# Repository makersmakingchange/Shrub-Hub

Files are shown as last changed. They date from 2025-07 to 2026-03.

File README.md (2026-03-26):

<!--- Open Source Assistive Technology: GitHub Readme Template Version 1.2 (2024-May-27)  --->

<!--- TEMPLATE INTRODUCTION --->

<!--- INSTRUCTIONS --->
<!--- This is a markdown template for creating the README.md file in a GitHub repository. This file is rendered and displayed automatically when someone visits the repository.

This document includes helper text that will not be displayed when rendered. Any text between the less-than sign + exclamation mark + three hyphen-minus (<!---) and matching three hyphen-minus + greater-than sign will not be displayed. This helper text can be deleted once the corresponding section is completed.

This template has a number of fields that can be searched and replaced with other text:
 - <Repository_Link> Replace this with the web address for the repository. e.g., (e.g., https://github.com/makersmakingchange/Open-Wobble-Switch))
 - <MMCWebLink> This is the website address including an alphanumeric id for the Makers Making Change Website. e.g., 01tJR000000698oYAA. This will come from MMC staff. 
Any text that is currently holding a space / is an instruction for the person filling in the README is in all capitals, to make it easier to see them in a rendered version.

--->
 
<!--- TITLE --->
# Shrub Hub
<!--- Should match the name of the GitHub repository. Choose something descriptive rather than whimsical.  --->

## Overview
<!--- A brief summary of the project. What it does, who it is for, how much it costs. --->
The Shrub Hub is an digital switch interface that allows a user to connect up to three 3.5mm assistive switches to a digital device like a computer or mobile phone. It has five modes, and can send keystrokes, mouse clicks, and media control commands, with five outputs per mode. It is designed to provide digital access to users using assistive switches, and to be low cost and very easy to build.

It is designed for use by those who have difficulty using traditional input devices like a computer mouse and may be especially useful for those with limited finger or hand dexterity.

The device is comprised of off-the-shelf electronics and 3D printed parts. There is no soldering or complicated assembly involved in building the device.

The Shrub Hub is open assistive technology (OpenAT). Under the terms of the open source licenses, the device may be built, used, and improved upon by anyone.

The overall cost of materials is about $35 (plus $8 for component shipping).

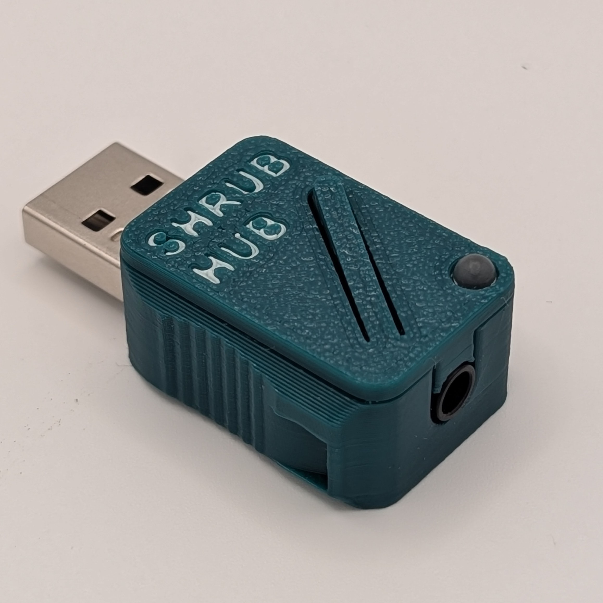
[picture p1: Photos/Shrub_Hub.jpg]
A Shrub Hub digital assistive switch interface consisting of a 3D printed enclosure with a USB-A connection on one end and a TRRS jack on the other.

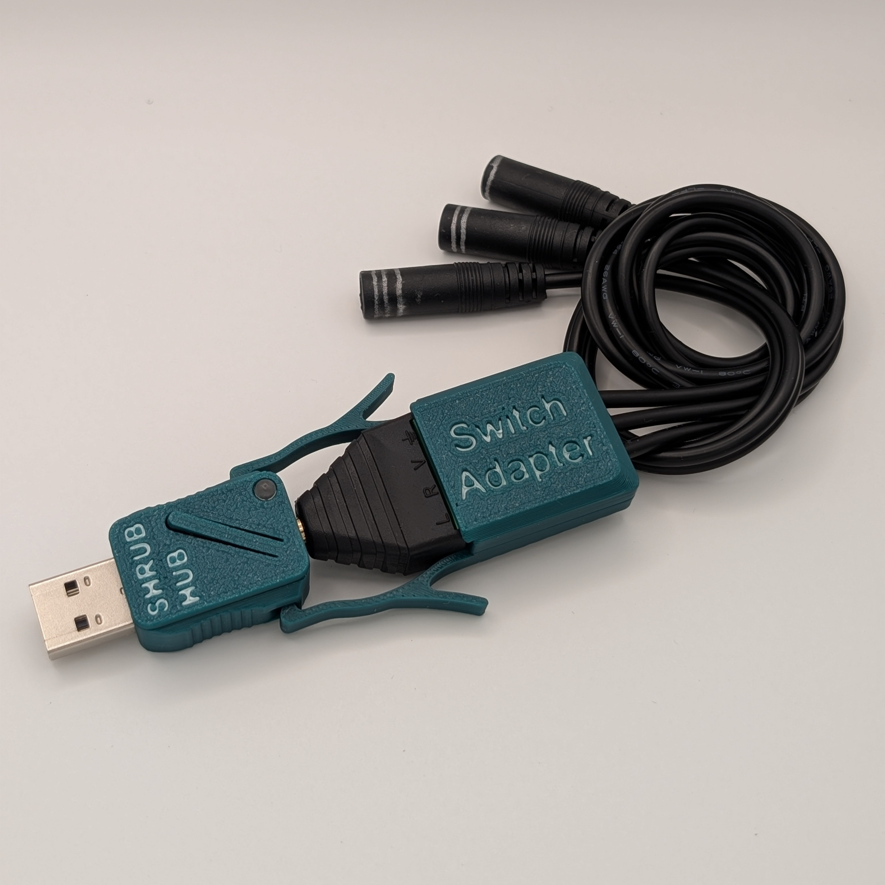
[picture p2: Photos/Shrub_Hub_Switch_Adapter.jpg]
A Shrub Hub with a 3-to-1 Switch Adapter attached to the TRRS connection on the Shrub Hub. The Switch Adapter has three cables attached, each with a 3.5 mm mono jack for connecting an assistive switch.

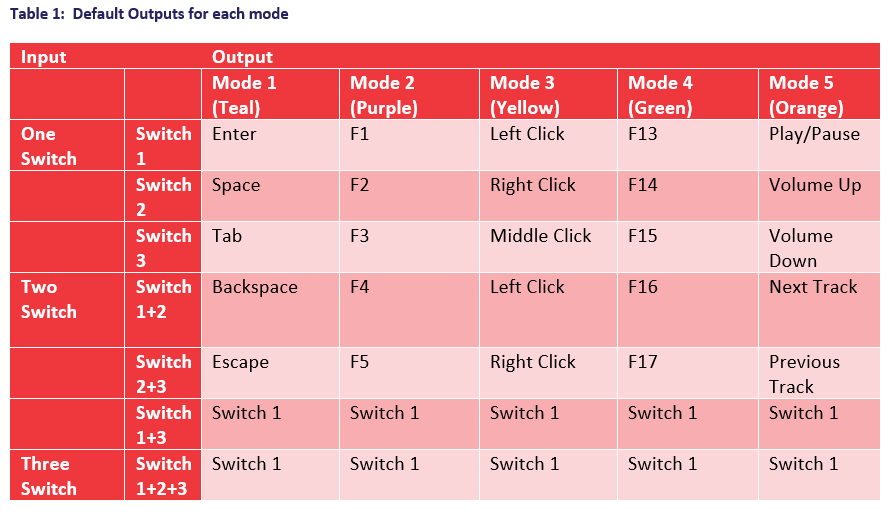
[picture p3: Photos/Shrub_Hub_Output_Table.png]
Table of Shrub Hub outputs.


## Makers Making Change Assistive Device Library
https://www.makersmakingchange.com/product/shrub-hub-digital-switch-interface/01tJR000009NpUT

## How to Obtain the Device
### 1. Do-it-Yourself (DIY) or Do-it-Together (DIT)

This is an open-source assistive technology, so anyone is free to build it. All of the files and instructions required to build the device are contained within this repository. Refer to the Maker Guide below.

### 2. Request a build of this device

You may also submit a build request through the [Makers Making Change Assistive Device Library Listing](<https://www.makersmakingchange.com/product/shrub-hub-digital-switch-interface/01tJR000009NpUT>) to have a volunteer maker build the device. As the requestor, you are responsible for reimbursing the maker for the cost of materials and any shipping.

### 3. Build this device for someone else

If you have the skills and equipment to build this device, and would like to donate your time to create the device for someone who needs it, visit the [MMC Maker Wanted](https://makersmakingchange.com/maker-wanted/) section.

## Build Instructions
<!--- Outline the major steps required to create a build --->

### 1. Read through the Maker Guide

The [Maker Guide](/Documentation/Shrub_Hub_Maker_Guide.pdf)  contains all the necessary information to build this device, including tool lists, assembly instructions, programming instructions and testing.

### 2. Order the Off-The-Shelf Components

The [Bill of Materials](/Documentation/Shrub_Hub_BOM.xlsx) lists all of the parts and components required to build the device.

### 3. Print the 3D Printable components

All of the files and individual print files can be found in the [/Build_Files/3D_Printing_Files](/Build_Files/3D_Printing_Files/) folder.

### 4. Assemble the Shrub Hub

Reference the Assembly Guide section of the [Maker Guide](/Documentation/Shrub_Hub_Maker_Guide.pdf) for the tools and steps required to build the device.

## How to improve this Device
As open source assistive technology, you are welcomed and encouraged to improve upon the design. 

## Files
### Documentation
<!--- Update the name, link, and version for documentation --->
| Document | Version | Link |
|---|---|---|
| Design Rationale | 1.0 | [Shrub_Hub_Design_Rationale](/Documentation/Shrub_Hub_Design_Rationale.pdf) |
| Maker Guide | 1.0 | [Shrub_Hub_Maker_Guide](/Documentation/Shrub_Hub_Maker_Guide.pdf) |
| Bill of Materials | 1.0 | [Shrub_Hub_Bill_of_Materials](/Documentation/Working_Documents/Shrub_Hub_BOM.xlsx) |
| User Guide | 1.0 | [Shrub_Hub_User_Guide](/Documentation/Shrub_Hub_User_Guide.pdf) |
| Quickstart Guide | 1.0 | [Shrub_Hub_Quickstart_Guide](/Documentation/Shrub_Hub_Quickstart_Guide.pdf) |
| Changing Outputs Guide| 1.0 | [Shrub_Hub_Changing_Outputs_Guide](/Documentation/Shrub_Hub_Changing_Outputs_Guide.pdf) |
| Changelog | 1.0 | [Changelog](CHANGES.txt) |

### Design Files
<!--- Include a copy of the original design files to facilitate easy editing and customization. Consider also including a generic format (e.g., STEP) --->
 - [CAD Files](/Design_Files/CAD_Design_Files)

### Build Files
<!--- Include a copy of the build files intended for manufacturing. This may include svg files for laser cutting, stl files for 3d printing, Gerber files for custom PCBs, and Arduino files for custom firmware. --->
 - [3D Printing Files](/Build_Files/3D_Printing_Files)
 - [Firmware Files](/Build/Firmware_Files)

## License
<!--- Add the year(s) for the copyright and the Designer Name. You may use the standard set of open licenses or choose your own for the hardware, software, and accompanying materials. --->
Copyright (c) 2026 Neil Squire Society.

This repository describes Open Hardware:
 - Everything needed or used to design, make, test, or prepare the Shrub Hub is licensed under the [CERN 2.0 Weakly Reciprocal license (CERN-OHL-W v2) or later](https://cern.ch/cern-ohl ) .
 - All software is under the [GNU General Public License v3.0 (GPL-3.0)](https://www.gnu.org/licenses/gpl.html).
 - Accompanying material such as instruction manuals, videos, and other copyrightable works that are useful but not necessary to design, make, test, or prepare the Shrub Hub are published under a [Creative Commons Attribution-ShareAlike 4.0 license (CC BY-SA 4.0)](https://creativecommons.org/licenses/by-sa/4.0/) .

You may redistribute and modify this documentation and make products using it under the terms of the [CERN-OHL-W v2](https://cern.ch/cern-ohl).
This documentation is distributed WITHOUT ANY EXPRESS OR IMPLIED WARRANTY, INCLUDING OF MERCHANTABILITY, SATISFACTORY QUALITY AND FITNESS FOR A PARTICULAR PURPOSE.
Please see the CERN-OHL-W v2 for applicable conditions.

Source Location: https://github.com/makersmakingchange/Shrub-Hub 

## Attribution
The Shrub Hub enclosure, software, and documentation was designed and created by the Neil Squire Society. 

The Shrub Hub incorporates the [Adafruit TRRS Trinkey - USB Key for Assistive Technology](https://www.adafruit.com/product/5954), a commercially available open source hardware device available for purchase through Adafruit and its distributors worldwide. The design of the TRRS Trinkey was a collaboration between [ATMakers.org](https://atmakers.org/) and [Adafruit](https://www.adafruit.com/). The hardware design files are released under the CC-BY-SA 3.0 license and are available at https://github.com/adafruit/Adafruit-TRRS-Trinkey-PCB. This device is also certified open hardware by the Open Source Hardware Association (OSHWA), certification [US002639](https://certification.oshwa.org/us002639.html).

The Shrub Hub is programmed in [CircuitPython](https://circuitpython.org/) using the [Mu Python Editor](https://codewith.mu/).

<!--- This is the attribution for the template. --->
The documentation template was created by Makers Making Change / Neil Squire Society. It is available at the following link: [https://github.com/makersmakingchange/OpenAT-Template](https://github.com/makersmakingchange/OpenAT-Template)

### Contributors
<!--- List the names of the people that contributed to the design. This could include the original source of the idea, designers, testers, documenters, etc. --->
 - Brad Wellington. Shrub Hub Enclosure, firmware, documentation. Neil Squire Society / Makers Making Change.
 - Bill Binko. TRRS Trinkey PCB design and Learning Guide. [ATMakers.org](https://atmakers.org/).
 - Chris Young. TRRS Trinkey PCB Design. [ATMakers.org](https://atmakers.org/).
 - Eric Chau. Testing. Neil Squire Society / Solutions.
 - Jake McIvor. Documentation, testing. Neil Squire Society / Makers Making Change.
 - Limor Fried. TRRS Trinkey PCB Design. [Adafruit](https://www.adafruit.com/).
 - Liz Clark. TRRS Trinkey Learning Guide. [Adafruit](https://www.adafruit.com/).
 - Jody Dickerson. Testing. Neil Squire Society / Solutions.
 - Josie Versloot. Testing. Neil Squire Society / Makers Making Change.
 - Stephan Dobri. Testing. Neil Squire Society / Makers Making Change.
 
## Open Source Hardware Certification

The Shrub Hub has been certified as open source hardware by the Open Source Hardware Association under the OSHWA UID [CA000073](https://certification.oshwa.org/ca000073.html).

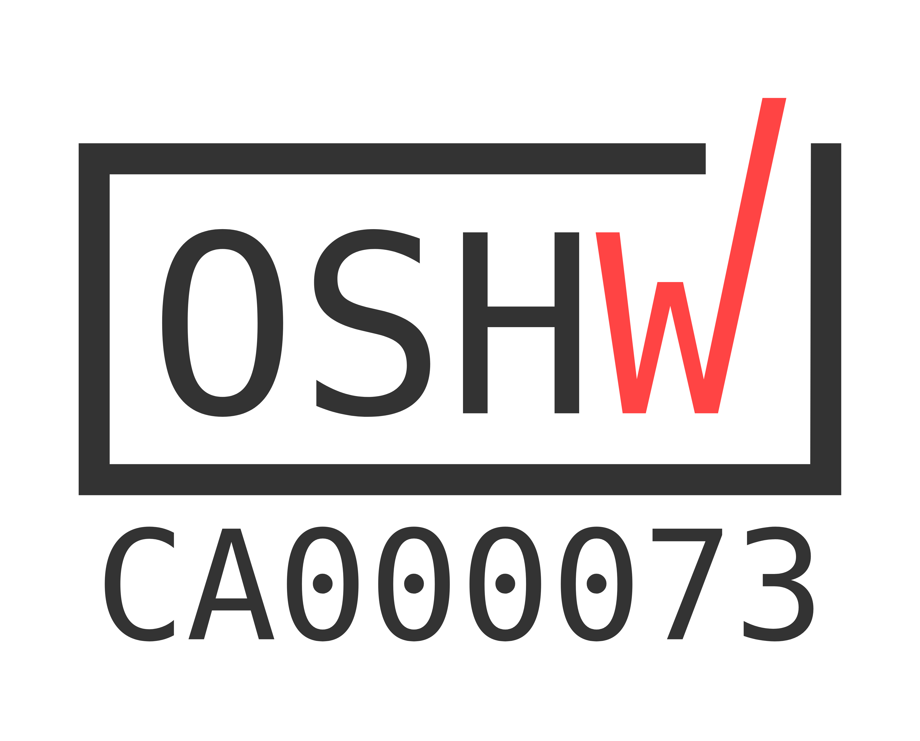
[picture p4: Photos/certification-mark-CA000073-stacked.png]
Open Source Hardware Certification Mark for Shrub Hub: CA000073
 

---

<!-- ABOUT MMC START -->
## About Makers Making Change
[Makers Making Change Logo](https://www.makersmakingchange.com/)

Makers Making Change is a program of [Neil Squire](https://www.neilsquire.ca/), a Canadian non-profit that uses technology, knowledge, and passion to empower people with disabilities.

Makers Making Change leverages the capacity of community based Makers, Disability Professionals and Volunteers to develop and deliver affordable Open Source Assistive Technologies.

 - Website: [www.MakersMakingChange.com](https://www.makersmakingchange.com/)
 - GitHub: [makersmakingchange](https://github.com/makersmakingchange)
 - Bluesky: [@makersmakingchange.bsky.social](https://bsky.app/profile/makersmakingchange.bsky.social)
 - Instagram: [@makersmakingchange](https://www.instagram.com/makersmakingchange)
 - Facebook: [makersmakechange](https://www.facebook.com/makersmakechange)
 - LinkedIn: [Neil Squire Society](https://www.linkedin.com/company/neil-squire-society/)
 - Thingiverse: [makersmakingchange](https://www.thingiverse.com/makersmakingchange/about)
 - Printables: [MakersMakingChange](https://www.printables.com/@MakersMakingChange)

### Contact Us
For technical questions, to get involved, or to share your experience we encourage you to [visit our website](https://www.makersmakingchange.com/) or [contact us](https://www.makersmakingchange.com/s/contact).
<!-- ABOUT MMC END -->

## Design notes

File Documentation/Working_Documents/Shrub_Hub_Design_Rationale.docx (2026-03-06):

# Overview

The Design Rationale is intended to provide designers and maker information about the design process and design decisions behind the development of the Shrub Hub, a cheap, easy to assemble switch access hub.

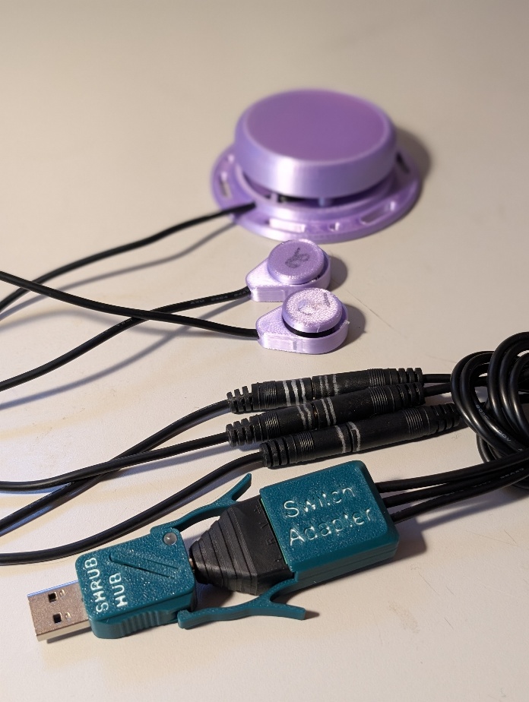
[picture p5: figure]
The Shrub Hub with the Switch Adapter connected to three assistive switches
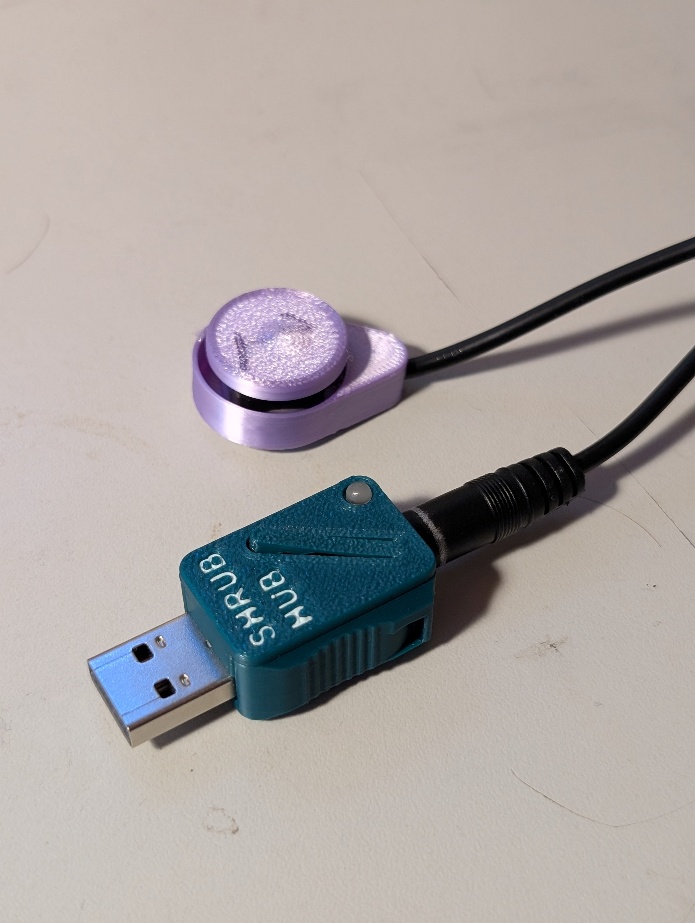
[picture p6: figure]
The Shrub Hub connected to a single assistive switch

# Introduction

Many people experience difficulty using standard input devices such as keyboards, mice, or touchscreens due to physical, cognitive, or sensory limitations. Assistive switches provide an alternative way to interact with technology by allowing users to control digital devices through simple, reliable actions such as pressing a button, activating a sensor, or triggering a switch with minimal movement.

To be useful, assistive switches must connect to computers, tablets, and other digital systems in a way that the device can recognize as input. While commercial switch interfaces exist to provide this digital access, they are often expensive, limited in customization, or difficult to obtain, creating a barrier for many users, families, schools, and support organizations.

This project presents a low-cost, easy-to-build digital switch interface designed to increase access to assistive switch technology. The device allows users to connect one or more assistive switches to common digital devices, enabling interaction with software, communication tools, and other technology. By focusing on affordability, simplicity, and accessibility, this design aims to reduce barriers to digital access and support a wider range of users in engaging with technology on their own terms.

The Shrub Hub is a USB Assistive Switch Interface based on the Adafruit TRRS Trinkey (https://www.adafruit.com/product/5954) hardware, a USB Key with a 3.5 mm jack and a microcontroller that was created based on a request from ATMakers (https://atmakers.org/), and the Adafruit Learning Guide (https://learn.adafruit.com/using-the-trrs-trinkey-as-an-assistive-technology-device/assembly) by Chris Young and Bill Binko.

# User and Interest-Holder Needs

ID | Need | Interest-Holder
UN01 | I need to be able to control my computer with minimal switches | Primary User
UN02 | A device that doesn’t require a soldering iron or PCB is easier to build | Maker
UN03 | I want a device that is easy to set up | Secondary User
UN04 | I want a device that I can customize to my needs | Primary User
UN05 | An inexpensive switch interface | Primary User, Secondary User

# Design Input

## Requirements

The goals and requirements outlined here can be used to assess if a device would meet the needs of a user and determine when a design is sufficient for release.

### Goals

G01 | Create a low-cost switch interface
G02 | Create an easy to build switch interface
G03 | Compatible with a computer without installing software
G04 | Create a portable switch interface

### Requirements

F01 | Device must accept at least two 3.5 mm switch inputs
F02 | Device must output HID keystrokes to the connected device

### Evaluation Criteria

1. Durability
2. Reliability
3. Minimize cost
4. Minimize print time
5. Minimize material usage
6. Minimize number of individual 3D printed parts

### Constraints

C01 | Device cannot use a custom PCB
C02 | Device cannot require soldering

## Research

Research was conducted as part of the update for the Switch Interface 101 resource.

### Commercially Available Options

Options that can be purchased but not made by a maker.

#### Swifty

Title / Name of device | Swifty
Link | https://www.orin.com/access/swifty/
Author | Origin Instruments
License | N/A
Cost | $99 USD

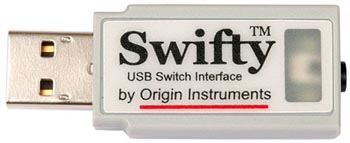
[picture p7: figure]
The Swifty Digital Switch interface on a white background

Figure 1: Swifty Switch Interface

The Swifty is a digital switch interface that can connect up to two 3.5 mm switches, or up to three wireless ‘Beam’ switches. It can be used to send keystrokes to a connected device for switch scanning or computer control.

Requirements Met | Requirements Unmet
F01, F02 | G01

##### Useful Design Features

Using three switches instead of two opens more options for computer control.

### DIY / Maker-Friendly Options

Options that can be made by a maker.

#### Rocket Switch

Title | Rocket Switch
Link | https://www.makersmakingchange.com/s/product/rocket-switch-interface/01tJR000000694SYAQ
Author | Neil Squire Society
License | Attribution-ShareAlike4.0 International
Cost | $50 CAD
Test Build (Y/N) | Y
Add to Library (Y/N) | Y

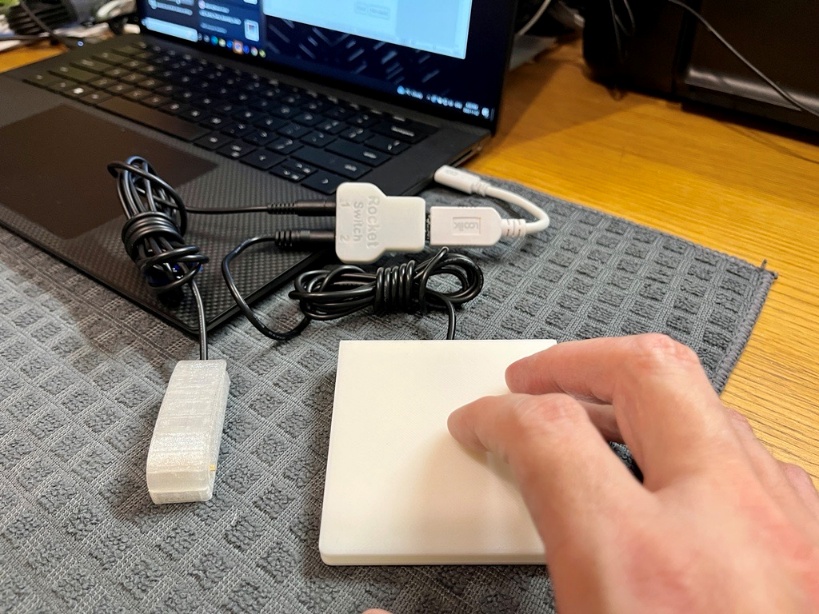
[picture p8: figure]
A hand pressing on a white assistive switch plugged into the Rocket Switch, which is plugged into a black laptop.

Figure 2: Rocket Switch Interface

The Rocket Switch is a USB switch interface that accepts up to two 3.5 mm switches to send keystrokes to the connected device.

Requirements Met | Requirements Unmet
G01, F01, F02 | C01, C02, G02

##### Useful Design Features

The modes feature of the Rocket Switch was taken and added to the Shrub Hub.

# Prototyping

## Initial Prototype

The initial version as published on the Adafruit site.

### Physical Component / Enclosure

The enclosure used on the device was provided by Adafruit. The version used was the FDM printed version, although they also provide an SLA compatible version.

The case can be found at the following link: The Case (https://learn.adafruit.com/adafruit-trrs-trinkey/downloads).

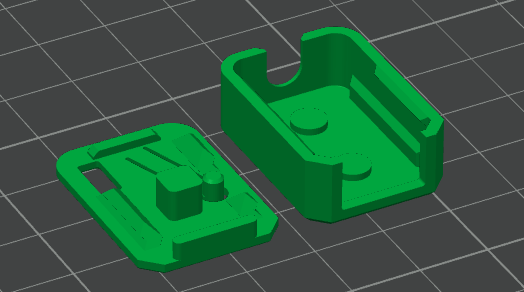
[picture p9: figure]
The TRRS Trinkey enclosure files open in a slicer program. The enclosure is in green, on a black grid background

Figure 3: Adafruit TRRS Trinkey Enclosure

### Electrical Components

Part | Image | Price | Link

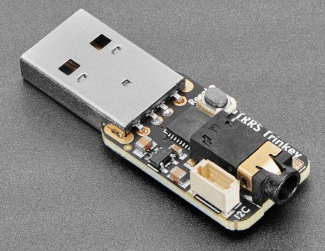
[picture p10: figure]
Angled Shot of the Adafruit TRRS Trinkey.

Adafruit TRRS Trinkey | | $9.95 USD | Link (https://www.adafruit.com/product/5954)

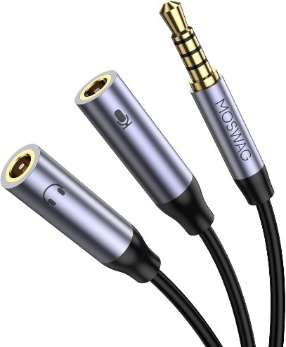
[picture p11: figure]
Close up of microphone splitter cable

Microphone Splitter Cable | | $10.99 CAD | Link

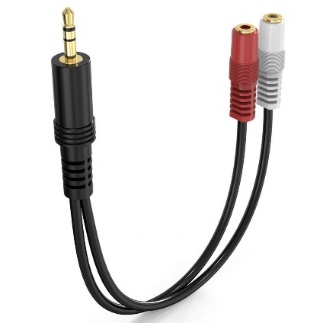
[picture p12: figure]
Close up of stereo to mono splitter cable

Stereo to Mono Splitter | | $9.99 CAD | Link

### Code Structure / Function

Code used for the initial version was the supplied code in the project repository called TRRS_Switch_Control (https://github.com/cyborg5/TRRS-Trinkey-Mouse-and-Keyboard-Emulator/tree/main/code) on GitHub.

The code scans the connected buttons and determines which output to send depending on the combination of switches pressed. The software recognizes the 3 individual switch presses and has an additional 2 outputs from chorded inputs, with another 2 chords recognized but not implemented.

## Prototype Decisions

Prototype | Decision (Abandon, Modify, Proceed) | Justification
Initial Prototype | Modify | Missing some functionality.

## Second Prototype

The second prototype was developed based on the feedback received from the user testing. It involves changes to both the enclosure and the firmware.

### Physical Components/Enclosure

An enclosure was developed to replace the one supplied by Adafruit for the TRRS Trinkey. This enclosure kept the same basic shape, with the snap-on lid with a flexible arm for the reset button, but several key changes were made.

The final enclosure has the lever arm, a light pipe for the NeoPixel LED, a USB-A connector, a TRRS plug, grippable spots on either side, and clip spots for attaching the TRRS breakout.

The TRRS breakout enclosure covers the TRRS terminal splitter and the cables. It prevents force on the cables from transferring to the screw terminals and makes a mechanical connection to the microcontroller that is sturdier than just the TRRS connection.

A new enclosure was developed that has the name of the device on it that includes a light pipe and covers the unused i2c port.

After user testing, a number of issues were raised about this enclosure. The testers found that:

- It could be difficult to unplug the device
- Light pipe was more ‘tactile’ than the reset button, leading to people pressing the light pipe
- Connection between Switch Adapter and the main device seemed weak
- Cable ties could be poorly trimmed by a maker and remain sharp

To resolve these issues, the enclosure was modified to raise the arm of the reset button beyond the plane of the lid so that it was more tactile, and a grip was added on either side of the enclosure to make it easier to remove. Two detents were also added to allow the Switch Adapter to attach better.

The Switch Adapter was redesigned to add two snap fit arms that attach to the enclosure, a set of internal deformable arms that secure the cables and replaced the cable tie with snap fit arms to hold the enclosure together.

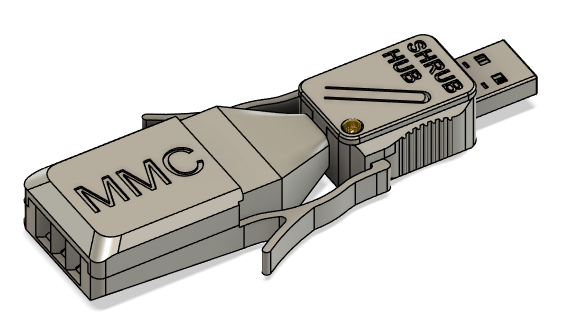
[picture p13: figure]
A CAD model of the Shrub Hub and Switch Adapter

Figure 4: Shrub Hub and Switch Adapter Enclosure

### Electrical Components

A piece of feedback received from the tester was that they would like to use the Shrub Hub with a single switch. The version that was given to the tester used the ring 2 as the common ground because that was the wiring used in the original Adafruit code, but plugging in a mono cable switch to this would short ring 1 and sleeve to ring 2, reading as switches 2 and 3 constantly being pressed down.

Version | L Terminal | R Terminal | V Terminal | Ground Terminal
Original | Switch 1 | Switch 2 | Ground | Switch 3
First Single Switch | Ground | Switch 1 | Switch 2 | Switch 3
Second Single Switch | Ground | Switch 2 | Switch 1 | Switch 3

To make this one switch version possible, the common ground was switched to the tip of the connector. This required the rewiring of the Switch Adapter to move the common ground, as well as some changes to the software. The ring 2 pin was changed to an input, while the tip was changed to an output. The switch detection function was modified to remove the tip, add ring 2, and change ring 1 to switch 1, ring 2 to switch 2, and sleeve to switch 3. Finally, since pressing a mono switch with this wiring would press all three switches, the chording needs to be added to handle this.

The original code recognized switch 6 (switch 1 + 3) and switch 7(all three switches) but since they were not included in the keystroke matrix, the code does not send switch 6 or switch 7 to the keystroke compiler. Since the mono cable switch detects as switch 7, an else statement was added to make both switch 6 and 7 use the switch 1 entry in the keystroke matrix. It is possible to also add entries for switch 6 and 7 to the keystroke matrix, but due to the memory issues that the microcontroller faces, it was decided to test the one switch version before dealing with the memory management.

Once these changes were made, the device was tested with the switch plugged directly into the microcontroller, and it behaved as expected. The device was tested again using the Switch Adapter to ensure that it still functioned as before, and no issues were detected.

The one thing that stood out was the different behaviour when using a switch with a TRS jack instead of a mono jack. When using the TRS jack, pressing the switch only connects the ring 2 and sleeve to ground instead of all three, which is read by the device as switch 5, which is already programmed into the device. This does not throw any errors, but a user who does not know the difference between a mono cable and TRS cable and is expecting switch 1 might be confused as to why they are getting switch 5, especially if switch 5 is a ‘non character’, like the escape key or function keys.

To resolve this issue, rings 1 and 2 were swapped, with ring 1 becoming switch 2 and ring 2 becoming switch 1. This causes a TRS switch to read as switch 6 when pressed, which behaves the same as switch 1, resolving the issue.

#### Alternate Parts Sourcing

When reviewing the parts in the Bill of Materials, we saw an opportunity to source the parts for the Switch Adapter through Digikey to simplify the ordering process and protect against the unreliability of Amazon sellers.

When looking for alternate parts on Digikey, we were unable to find exact replacements. Adafruit sold a TRRS terminal splitter, but it was significantly smaller than the one purchased from Amazon. There were also no direct equivalent to the mono cables, although there were similar 6ft long TRS cables that were ordered instead.

Once the parts arrived, a Switch Adapter was constructed and compared to the one made with Amazon parts. The first problem was the size of the TRRS splitter. The Adafruit on was significantly smaller, and requires a smaller screwdriver and the size of the openings on the terminal were much smaller. The Digikey cables were about a millimeter in diameter larger than the Amazon cables and had the ground wire as a wrapping of loose copper wires around the signal wires, wrapped in a metal foil.

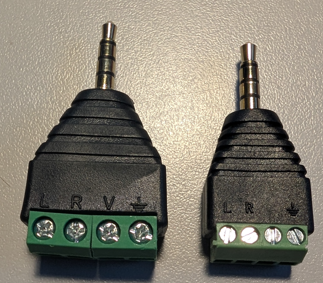
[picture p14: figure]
A side by side size comparison of the Amazon and Digikey TRRS terminals from the top
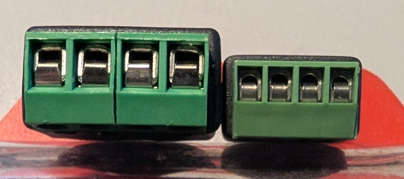
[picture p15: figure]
A side by side size comparison of the Amazon and Digikey TRRS terminals from the side

When attempting to build the Switch Adapter, there were several problems that appeared. The first problem was with the screw terminals, using a screwdriver that was slightly undersized for the terminal size strips the flathead connector on the terminal block, the screwdriver used needs to be the largest possible one that can fit in the hole for the screw. The terminals themselves are also undersized, unable to fit the twisted copper ground wire from one of the wires, let alone three. The cables were also worse than the Amazon equivalent, being six feet long and TRS, instead of two feet and mono. When cutting down the cables and trimming them, the ground connector was a collection of copper wires wrapped around the signal wires which were themselves wrapped in a metal foil. These took significantly more work to prepare than the precut and prestripped Amazon cables, and resulted in an extremely bulky and fraying ground cable that did not fit in the terminal.

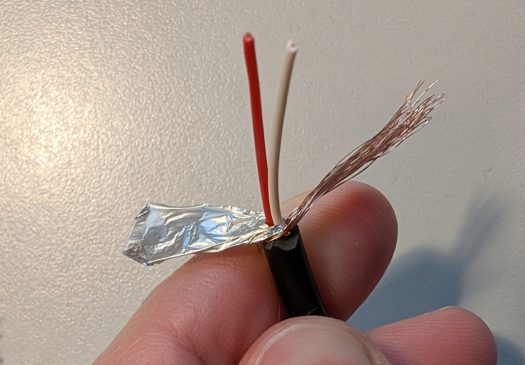
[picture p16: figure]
The digikey cable stripped
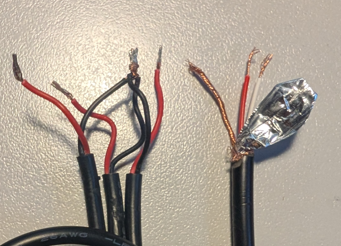
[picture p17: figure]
A side by side of the old cables vs the stripped amazon cable

After this, the decision was made to continue with the Amazon components for easier makeability.

#### Limitations of the TRRS Trinkey

While the TRRS Trinkey microcontroller is designed for use with Assistive technology, it does have its limitations.

The largest limitation that was encountered during development was the memory available on the board. The board has 32 KB of RAM, and this gets used quickly. When developing the code, this memory limit was frequently hit. This memory limit was reached when there was still between 1-2 KB of memory remaining on the board, due to memory fragmentation where there is memory still left on the board, but not a single continuous section of memory able to store whatever the user is currently trying to store. The CircuitPython program does not have any defragmentation tools, so this issue prevented the settings file from being on a separate user editable file, as there was not room on the board to add a function to read it into memory. There are garbage cleanup tools available however, which remove unused variables from memory to free up as much space as possible.

As a consequence of the limited memory, various libraries and sub library functions such as settings.toml, are not supported on the board.

Another limitation faced was the hardware on the board. The board has six pins tied to the TRRS jack, one for each ring, one to for the tip switch, and one for the ring 1 switch. There is also a reset button on the board, an i2c plug, and a NeoPixel. Beyond this, there is no way to connect to the microcontroller. When the idea was raised of a separate mode button on the device instead of holding a switch input, there was no way to easily do this. It would have required either adding a separate i2c button board, or holding the reset button while plugging in the board.

### Code Structure/Function

#### Time Monotonic Issue

A potential issue with the code is the use of time monotonic in the key press function. Time monotonic is used to track the duration of a keypress and determine when a key press reaches the mode change threshold. However, time monotonic is a 64-bit millisecond tick counter, and begins to lose precision after 2^22 milliseconds, (https://docs.circuitpython.org/en/latest/shared-bindings/time/) or about 1.165 hours. At 2^23 milliseconds, it will change every 2 milliseconds, and so on. More precise measurements of time, such as time.monotonic_ns() are not available on the Trinkey TRRS due to the lack of long integer support (https://learn.adafruit.com/adafruit-trrs-trinkey?view=all).

However, initial testing with leaving the device powered on for 16 hours it still took the same 4 seconds to change mode, which is roughly 2^25.8 millisecond, which should take 8 milliseconds per tick instead of 1, or 32 seconds to change the mode. More testing is needed to determine how the device will function after long periods of time powered on. A blink test was suggested, where the Neopixel turns off and on at regular intervals, and can be informally monitored over time to track the change in the timing.

#### Adding User Adjustable Settings

Figure 5: Supported CircuitPython Libraries for the Trinkey TRRS

One of the OFIs identifies was to add a settings file to allow the device to remember the mode after a reboot, and to make it easier for a clinician to change keystrokes or other settings without risking them breaking the code by changing the wrong section.

The requirements for a user adjustable setting file are:

- File must allow comments: Comments are needed to let the user know how to adjust the file, what they can and cannot change in the file
- File should be human readable: If the user is opening and changing the file, they should be able to read and understand the file
- File should be forgiving of simple formatting errors: Since the user will likely be editing the file in a text editor and not a proper IDE, an extra whitespace or newline shouldn’t break the file

In CircuitPython, the two main ways of doing this is with a settings.toml file, or with a text file that you parse.

In CircuitPython, a settings.toml file is used to separate settings from the main code.py file to allow the main code to be shared without also sharing personal information, such as passwords or network settings. It supports comments, and is essentially an extension of the main code file used to declare variables. Unfortunately, although it supports the OS library, the TRRS trinkey specifically does not support the use of settings.toml (https://docs.circuitpython.org/en/latest/shared-bindings/os/)

CircuitPython also allows for a txt file stored on the microcontroller to be read by the main program. While writing requires the board to be set to be read only to the computer, the text file can be read without changing settings on the board in a boot file.

If the data in the txt file is in JSON format, if can be easily read into the code using json.load. However, json does not support comments, is fairly rigid in its formatting, and is not very user parsable. JSON is also not available on the Trinkey TRRS (https://docs.circuitpython.org/en/latest/shared-bindings/support_matrix.html), a custom parser would need to be developed

YAML is a more user-friendly version of JSON that supports comments, but there is not a built in YAML parser the way that there is a JSON parser. A custom ‘YAML lite’ parser could be developed for the parts used in the keycode matrix.

Finally, a custom format can be developed for this specific use case, and a parser developed for it. This would take the most development time out of all the options, but provide the most flexibility and customizability. An initial test showed that integers read from a text file can be used to send keystrokes, but so far, keycode objects cannot be stored in the text file and used to send keystrokes. Having the keystrokes stored as integers instead of human readable words would run counter to the goal of having the keystrokes in a separate file to make it easier for a maker to modify the keystrokes.

Options | Pros | Cons
Settings.toml | - Supports comments - Written in Python, allows declaring the list exactly as it would be written in the main code - User can swap files to get a different set of keystrokes - User doesn’t have to open or make changes to the main file at all | - Not supported by the Trinkey TRRS
JSON | - Existing CircuitPython parser - User can swap files to get a different set of keystrokes - User doesn’t have to open or make changes to the main file at all | - Built in circuitpython JSON parser is not supported by Trinkey TRRS - Would need to develop a stripped back parser - Comments are not supported by the standard - Standard is not very human readable
YAML | - Standard supports comments - Standard is more human readable - User can swap files to get a different set of keystrokes - User doesn’t have to open or make changes to the main file at all | - Circuitpython does not have a built in YAML parser - Would need to develop a stripped back parser
Custom | - Would allow the creation of a standard that worked the best for the type of data we are storing - User can swap files to get a different set of keystrokes - User doesn’t have to open or make changes to the main file at all | - Would need to develop a custom parser - Can’t just read in keystrokes from file, need a way to convert them from strings
Leave keystroke matrix in | - Do not need to develop a custom parser - Do not need to develop a method to convert a string into a keycode object - Supports comments | - User will have to open and make changes to the main file

Recommendation

While breaking out the keycode and other user settings into a separate file is a good idea, the limitations of the TRRS Trinkey eliminate the best options. A settings.toml file would be the easiest, most user friendly method, but does not work with the Trinkey. The same issue is present with using a JSON file, as the Trinkey does not support the CircuitPython JSON parser.

This leaves us with developing a limited parser that can read the data in the text file. At this point, the format can either be JSON, YAML, or a custom data format. Using JSON or YAML, code can be reused from an existing parser, but stripped back to work with the limitations of the hardware.

Developing a custom parser would take significant development time, and require optimization to fit in the hardware limitations of the microcontroller. It would also need error handling and edge case detection.

The recommendation for the Shrub Hub is to leave the keystroke matrix in the code.py file. The fact that none of the standard plug and play options would work, requiring a custom developed parser vastly increases the amount of development time required, for a small improvement to the user experience.

Implementation

When trying to add a series of dictionaries to the main code to allow strings to be associated with the corresponding code object, the memory limit of the board was reached. After removing the dictionaries, the available memory left was revealed to be 2528 bytes. However, just the dictionaries measured in another file only took 1312 bytes.

Some research indicated that this may be due to fragmented memory, where there is not a large enough continuous location in memory for the dictionary, even though there is enough total room for them. (https://learn.adafruit.com/memory-saving-tips-for-circuitpython/reducing-memory-fragmentation)

Both declaring the dictionary at the beginning of the code, and frequent garbage collection were unable to make the dictionaries work. It also did not work when replacing the keycode.item calls with the integer values that they represent.

Another attempt was made to implement the settings closer to how they were handled in the Enabled Controller Mini CircuitPython version, with a section of the code dedicated to settings and separated from the rest of the code. In this section the individual button presses for each mode were broken out into their own variables, and all user modifiable settings were moved to this section. A declaration was added to then compile the keystroke matrix out of the component variables in the settings section. However, even this led to memory errors, as the addition of the extra variables for each keystroke entry caused memory issues.

Finally, an attempt was made to compile the code into a .mpy file, precompiling it to reduce the RAM usage and fragmentation using mpy-cross. The code was precompiled in powershell using “./mpy-cross code_name“ and loaded onto the Shrub Hub as a library. The main code file was then changed to be “import code_name” (this does not work if the .mpy file is named code.mpy). The code used for this was a version of the code that read the keystrokes from a text settings file. However, even after being precompiled, the code still did not have enough memory. Another attempt was made, removing the settings file and keeping the settings in the main file while everything else was kept in the library. This was also unsuccessful.

At this point it was decided that the original single file code should be used for the initial release.

#### Persistent Mode

To allow the mode to persist across reboots, a method was found to write to a non-volatile memory (nvm) byte array. While Adafruit says that it shouldn’t be possible to access non-volatile memory in circuitpython in non-express boards, the byte representing the mode was able to be stored to microcontroller.nvm[0].

# Testing

## Test Methods

### Test Switches

After connecting all switches to the commercial splitter cables, the device was plugged in and tested.

## Test Results

Initially, there was an issue where one key was consistently pressed down. This was determined to be caused by the mono TS cable used in the switches being consistently shorted by the microphone splitter cable. As a temporary workaround, the switch was replaced with another switch that used a TRS jack that would not be shorted.

Once the cables were working, it was found that the software worked as described, sending u/d/s/l/r when the correct switch/chord was pressed.

## User Testing

Two Shrub Hubs were sent to a pair of occupational therapists for testing. The initial pair sent were both programmed in Arduino but follow up instructions were sent to help with reprogramming the device in Circuit Python once that code had been developed. After the testers had the devices and used them with clients for about a month, a meeting was scheduled to get feedback on the devices

### Feedback Questions

General Questions

- Inputs
  - Is 3 inputs enough? Too few? Too many?
    - I think 3 is good, most people will remember 3 macros, ties into a next/back/select type system for a lot of different systems
  - Were there times that you needed additional inputs?
    - I have used more than 3 inputs for macros but have never yet needed it as buttons instead of a number pad or macro board
- Chording
  - Were you able to use the chording?
  - Were you able to test with a user? Were they able to use chording?
    - Not yet
  - Would it be beneficial to add 2 more chorded inputs (1+3, 1+2+3)
- Enclosure
  - Do you have any thoughts or issues with the enclosure of the TRRS Trinkey?
    - It’s good. I did try using it after putting lotion on my hands though and it was hard to remove, a few people might benefit from extra grip to pull it out, but mostly the user is not going to be the one connecting and disconnecting it.
    - A tactile label on the reset button would be helpful, visually it’s not that clear where to press
  - Do you have any thoughts or issues with the enclosure of the mono cable splitter?
    - I worry a little about the connection between the 2 getting bumped or pressed on and breaking the mono jack, it’s not very stable . This could also happen easily when thrown in a bag.
    - I worry a little that some creators won’t do a good job smoothing the ends of the cut zip ties, those can be really sharp if not cut carefully
    - It would be good to have the splitter mesh more with the trinkey, maybe with clips to prevent disconnection
  - Did you have any issues telling what mode the device was in/seeing the light pipe when the device was plugged in?
    - No, but younger user had trouble holding for 4 seconds (kept rushing it)
  - Was the size of the combined trinkey + splitter too big?
    - No. a right angle adapter could be used if needed?
- Getting the right input
  - Did you have any issues telling which switch input connected to which switch output?
    - No, your ring labels are clear and once the device is connected and programmed my memory moves to which switch color, not what number it is.
- Number of modes
  - Did you have any thoughts on the number of modes?
  - Did you find any of the modes unnecessary?
    - Never used 12345, too much chance for confusion
  - Were there any modes that you wanted but were not in the device?
    - mouseclicks
- Mouse clicks
  - Would mouse clicks be something you would want added?
    - Definitely, this is the most common use when pairing with something like a headmouse, and is effective to replace fine motor or finger control functions. Good for temporary disabilities
  - Would mouse movement be something you want added
    - Directional movement (pressing a button to move in the different directions)
      - I think that the other MMC joysticks already accomplish this
    - Morse mouse (Morse code to move the mouse around)
- Media control
  - Would media control (play/pause, skip, rewind, etc) be worth adding?
  - Would that be worth adding another mode for?
    - Yes, additional modes aren’t a burden for the user and most people wouldn’t reprogram them.
- Morse Code
  - Would morse code typing be worth adding?
    - I have only worked with one morse user and know of one more, both use a darcy/tandem master - I don’t think new users are adopting the technology very much.

Arduino Version

- Were there any issues changing the mode in Arduino mode?

Programming Circuit Python

- How would you describe the experience programming the hub with CircuitPython
  - Works well, it would be nice if there was a reminder of color within the matrix
- Were there any parts of programming the device that you found confusing or had questions about?
  - Double clicking button brings up a different boot menu
  - How to get out of boot menu/stop explorer opening folder

Circuit Python Version

- Were there any notable differences between this version and the Arduino version. If so, did they make the device better or worse
- Did you notice any issues with changing mode being slower after the device was plugged in for 2 hours? 4 hours?
  - Sorry, didn’t test it for that long yet ☹
- Were you able to change the keystrokes in the code?
  - Where you able to create a compound keystroke (like Win + H)

### Feedback Summary

- Three buttons is enough, a one button mode would be a nice addition
- Didn’t have an opportunity to test chording
- Trinkey was hard to remove from computer sometimes, enclosure is hard to grip
- Reset button should be more tactile/stand out more. Sometimes try to press the light pipe accidently since it sticks out more.
- Connection between splitter and hub is delicate, and worry about breaking it when throwing it into a bag
  - Maybe add some clips to make the splitter attach better
- Cable ties on splitter could be sharp if a maker doesn’t carefully trim them down
- Some younger users had difficulty holding it for 4 seconds and kept releasing too soon. Adding a blinking light when 4 seconds is up would help
- Right angle adapter might be useful but not necessary
- Ring labels on splitter are clear
- Didn’t use the 12345 mode, too much chance for confusion
- Really want the addition of mouse clicks
- Would want the addition of media control
- Don’t think that there’s much demand for morse typing
- When in circuitpython mode, device was easy to reprogram
- Would be nice to have a comment/reminder of the mode colour in each row of the keystroke matrix
- Accidently broke the code when trying to make changes, need to add a more in depth troubleshooting to the user guide about recognizing when the code is broken, since it is interpreted instead of compiled

OFIs

- Add gripable spots to the side of the enclosure
- Design a better enclosure for the splitter that does not rely on zip ties
- Create a stronger connection between the splitter and the hub
- Add mouse click mode
- Add media player mode
- Remove 12345 mode
- Improve troubleshooting section of user guide
- Better comments in the code
- Make it so the light flashes once 4 seconds holding the button is reached
- Make the reset button more tactile
- Save mode between reboots

# Design Output

## Naming

When choosing a name for the device, an effort was made to stay within the existing forest/tree theme for MMC joysticks and digital interfaces. A variety of names were brainstormed, such as Glade, Grove, Weald, and more names were suggested by the tester, such as Shrub, Arbor, Orchard, Leaf, and Twig.

Weald was eliminated first, as it was an obscure word that nobody knew. Grove was eliminated due to being the name of a connector by Seeed Studio, while Glade was eliminated to avoid overlap with the air freshener brand. From the remaining list of names, the name Shrub was chosen due to the connotations of being a small tree/plant.

The name of the add-on device that splits the TRRS jack into three mono cables was also something that needed to be determined. It was initially named the Switch Splitter, but the issue was raised that is sounded like a device that could be used to split one switch to instead control several devices. The following list of replacement names were brainstormed:

- Switch Adapter
- Splitzio
- Switch Breakout
- TripSplitz
- Switch Merger
- 3-in-1 Switcher
- 3-to-1 Switch
- 3-2-1 Switch
- 3-2-1/3-to-1 Merger

The decision was made to go with 3-to-1 Switch Adapter for this device.

## Detailed Design

### Overview

The device is comprised of two main parts, a TRRS Trinkey microcontroller in an enclosure, and a TRRS breakout connector that allows three assistive switches to be connected to the device. When connected to the computer, the device will send keystrokes when the connected buttons are pressed. It has five different modes with different sets of keystrokes, and the user can change between them by holding down a connected switch for four or more seconds. The different modes allow users to send screen navigation keystrokes such as space, tab, and enter, send the first five functions keys(F1-F5), perform mouse clicks, send the first five unused function keys(F13-F17) for custom hotkeys, and perform media control such as play/pause, volume up/down, and skip.

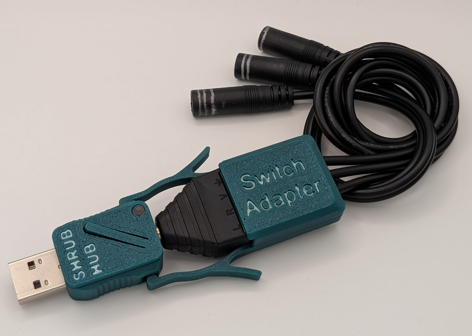
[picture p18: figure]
Final version of the Shrub Hub and Switch Adapter.

Figure 6: Finished Shrub Hub and Switch Adapter

#### Enclosure

Objectives:

1. Protects the internal board
2. Provides grip to more easily insert/remove the device.
3. Improves the aesthetics of the device
4. Provides a connection point for the Switch Adapter
5. Provides a place for labelling and branding

Requirements:

1. Hold the PCB securely
2. Show the mode LED
3. Provide access to the reset button

Criteria

1. As narrow as possible.
2. Minimal print time.
3. No or minimal tools required for assembly.
4. Aesthetic

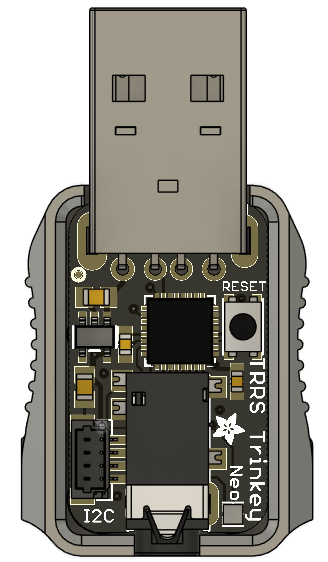
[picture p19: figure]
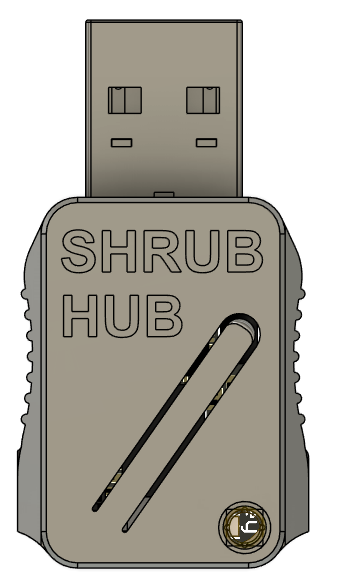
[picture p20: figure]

Figure 7: Shrub Hub with and without top of enclosure

The enclosure for the microcontroller is a two-part enclosure that uses a snap fit to connect the lid to the base. The microcontroller is held in place vertically by the fit of the two halves around the USB and TRRS connectors, and four pillars on the bottom that space the microcontroller from the bottom, and horizontally by the general shape of the base of the enclosure. There is ~0.23 mm of clearance between the walls of the enclosure and the sides of the PCB.

The enclosure keeps the flexible arm to activate the reset button from the original Adafruit enclosure, but the pillar that presses the reset button has deliberately been made too tall so the arm flexes out beyond the plane of the lid of the enclosure to provide a tactile locating feature to make it easier to press the reset button when the enclosure is not visible, such as when the device is plugged into the back of a computer.

A light pipe has been added to the lid of the enclosure, located over the microcontroller’s NeoPixel to allow the user to view the visual feedback from the light. The light pipe is held in place using a press fit.

Finally, the exterior of the enclosure has two concave detents with vertical ribs to make it easier to grip the enclosure while removing it from the computer, and two integrated snap fit pockets to connect to the Switch Adapter.

#### Switch Adapter

The TRRS Trinkey has a TRRS input. To use standard assistive switches with mono plugs, an adapter is required. There is a combination of commercially available adapters that can work, but they are expensive, only specific varieties will have the correct wiring, and the overall connection is not compatible with all assistive switches.

Using a custom adapter ensures that the device is compatible with all assistive switches. The adapter consists of an off-the-shelf TRRS terminal block, three mono cables with female jacks, and a 3D printed enclosure.

Objective

1. Provides an easy way to connect multiple mono switch connections to the TRRS input on the Shrub Hub

Requirements

1. Must be able to connect three 3.5 mm mono plugs in the correct wiring scheme to a 3.5 mm male TRRS plug.
2. Must be able to be assembled without soldering.
3. Mono switch connections must be labelled.

Criteria

1. Durable, reliable connection to Shrub Hub
2. Minimal size
3. Durability
4. Reliability

The Switch Adapter consists of a 3D printed enclosure, a screw terminal TRRS jack, and three female mono cables

The mono cables are attached to the screw terminals of the TRRS jack and allow the TRRS connection to be split out to the three mono cables with a common ground. The enclosure protects these connections and allows for the Switch Adapter to be more securely connected to the microcontroller enclosure.

The enclosure consists of two parts: a base that connects to the microcontroller enclosure and grips the mono cables; and a lid that attaches the enclosure to the TRRS jack. The two halves of the enclosure connect with a snap fit.

The base of the Switch Adapter has three primary features. The first feature is the two long arms that extend from the body of the splitter. When the TRRS jack is connected to the microcontroller, these arms clip into the detents in the body of the microcontroller enclosure and help to prevent the TRRS jack from being unplugged or coming loose. These attachment arms also feature two side arms that can be gripped to flex the enclosure arms to the side to detach them from the microcontroller enclosure. The second main feature of the base are the flexible arms that grip the three mono cables. Designed for use with 3mm mono cables, these arms flex out of the way, with the vertical ridges gripping the cable, preventing it from moving forwards or backwards. Finally, the base contains slots for the snap fit of the lid to attach.

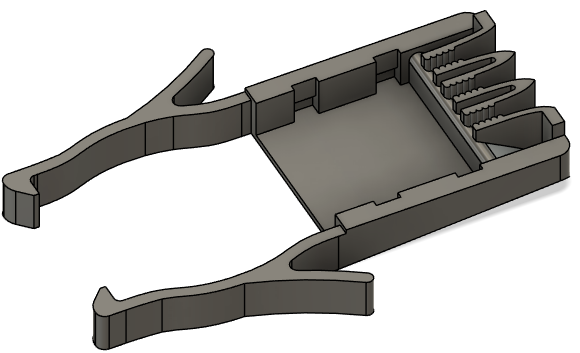
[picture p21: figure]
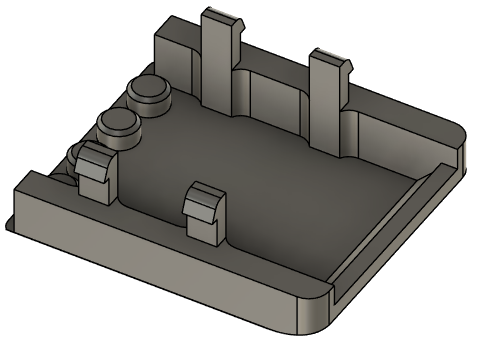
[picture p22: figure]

Figure 8: Top and Bottom of Switch Adapter Enclosure

The lid of the enclosure contains two main features, the snap fit arms that attach it to the base, and the four posts that help retain the enclosure on the splitter. The enclosure is assembled around the TRRS splitter, and the four posts are inserted into the holes of the screw terminal, preventing the enclosure from moving forwards or backwards relative to the TRRS jack. The enclosure is prevented from moving side to side by a combination of the posts and the fit of the enclosure around the jack and prevented from moving up and down by the fit of the enclosure around the jack.

### Electrical Components

After the issue with the mono cable switches shorting on the microphone splitter, an alternate splitter cable was created using a TRRS terminal jack and three pre stripped female mono cables. This option requires slightly more assembly but still does not require soldering. It is cheaper to build than the commercial splitter version and gets even cheaper when built in bulk.

Part | Image | Price | Link

Single Build

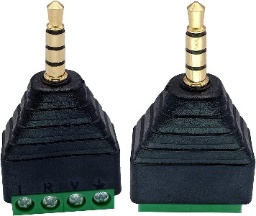
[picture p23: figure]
Two TRRS Terminal Jacks

TRRS Terminal | | $6.58/2 pack $3.28 Each | Link

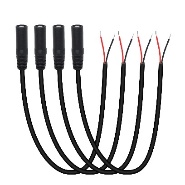
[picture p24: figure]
Four stripped mono cable jacks on a white background

Female Mono Cable | | $10.99/4 pack $2.75 Each | Link (http://www.amazon.ca/dp/B0BZWK7PLP)

Bulk Build

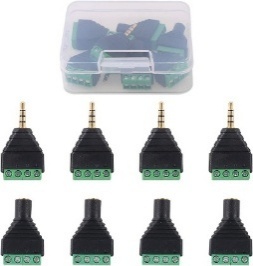
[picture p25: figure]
A plastic box full of TRRS Terminal jacks, with 8 more jacks laid out beneath it

TRRS Terminal | | $14.93/8 pack $1.86 Each | Link (https://www.amazon.ca/dp/B07KF8SRC3/)

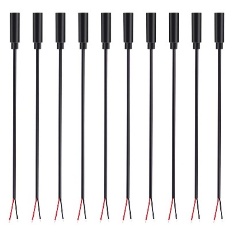
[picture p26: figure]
10 pre stripped mono cable jacks laid side by side.

Female Mono Cable | | $20.22/10 pack $2.02 Each | Link (https://www.amazon.ca/dp/B082VW97TT)

The final wiring of the TRRS adaptor is as follows, where the bolded section is the terminal on the TRRS plug, and the rest is the wire that is connected to it:

- L: Common ground for all three switches
- R: The signal cable for switch 2
- V: The signal cable for switch 1
- GND: The signal cable for switch 3

This configuration allows for a single switch to be plugged in to the Shrub Hub instead of the adapter and function as either Switch 6 or 7, depending on the cable type used on the single switch.

### Code Structure / Function

#### Overview

The code for the Shrub Hub is written in CircuitPython and can be easily loaded onto the device with minimal instructions, and settings easily changed. The code detects which combination of the three switches have been pressed and determines which keystrokes should be sent based on the combination of switches pressed.

#### Platform

The Shrub Hub was programmed using CircuitPython on the Mu IDE, as opposed to most MMC devices, which use ArduinoC. The decision was made to program the device in CircuitPython for several reasons. One of the largest reasons was to allow for the user to be able to change settings in the firmware easier, as the code is stored on the device and can be easily modified without needing to install anything. Programming in CircuitPython also allows the MMC team to build institutional knowledge on using CircuitPython and its limitations.

#### Operating Modes

The device currently has five different operating modes, based off the original operating modes of the Adafruit version, and feedback from the testers. The mode can be changed by holding down any connected switch for more than the mode change time, which by default is four seconds. Each mode by default has five different keystrokes, three of which are activated when pressing an individual switch, and two that are activated by pressing two switches at the same time. The default modes that the device is programed with are as follows:

- Mode 1: Enter/Space/Tab/Backspace/Escape
- Mode 2: F1/F2/F3/F4/F5
- Mode 3: Left Click/Right Click/Middle Click/Left Click/Right Click
- Mode 4: F13/F14/F15/F16/F17
- Mode 5: Play/Volume Up/Volume Down/Next Track/Previous Track

The keystrokes of mode one were chosen based on the research done on existing commercial hubs, as they were commonly found on most commercial hubs and can be used for basic computer navigation without needing any settings changed on the host device. Mode 2 keystrokes were taken from the MMC Enabled Controller. Mode 3 and 5 were added after feedback from testers, and mode 4 was added on the request of a tester who wanted unused keys that could be used with the AutoHotkey program to trigger different actions and programs.

After full release of the device one of the goals is to get feedback from users and clinicians about the range of keystrokes on the Shrub Hub and ensure that they meet the needs of the users.

#### Input Handling

When a switch is pressed, the NeoPixel is turned off, and the device waits until the switch is released. Once the switch has been released, if it was held for less than four seconds the device turns the NeoPixel back on and sends the appropriate output to the connected computer. If the switch was held for over four seconds, the mode changes, the colour of the NeoPixel changes, and no output is sent to the connected computer. It is important to note that the output is sent to the connected device when the switch is released, not when it is pressed.

The device checks for switch presses at 100Hz, or 100 times a second.

#### Operation

Once plugged in, the Shrub Hub reads the last stored mode from non-volatile memory, then enters the main loop. The main loop of the Shrub Hub firmware constantly checks to see if a button has been pressed. If it has, the program turns off the LED and checks to see which buttons have been held down and checks to see when they are released. Once the buttons have been held for longer than the mode change time, the LED comes back on. Once the buttons are released, if they were held for longer than the mode change time, the mode will change, the LED colour will update, the new mode will be logged to the non-volatile memory, and no keystroke will be sent. If the buttons were held for less than the mode change time, the buttons pressed will be sent to the keystroke compiler.

The keystroke compiler takes the buttons pressed and the mode and looks up the corresponding entry in the keycode matrix. The entry contains a number corresponding to the type of keystroke (keystroke, mouse click, or media control), as well as a series of keystrokes. From here, it will use the identifier number to determine which library to use and sequentially press and hold all the keys listed in the matrix entry. This is largely irrelevant for mouse and media control, which only use one key at a time, but allows combination keystrokes such as CTRL+C or CTRL+SHIFT+T. After all keys are pressed, the keystroke is sent, all keys are released, and the program returns to the main loop.

Currently, switches 1, 2, and 3 all have their own corresponding outputs, while the combination Switch 1+2 and switch 2+3 also have their own distinct outputs. Switches 1+3 and 1+2+3 send the same output as switch 1, as it allows for a single switch to be plugged directly into the TRRS jack on the Shrub Hub without the use of the Switch Adaptor and still function.

# Validation and Verification Plan

To verify and validate the Shrub Hub, we review the goals, requirements and constraints that were established at the beginning of the project and compare them with the finished device. At the beginning of the project, we established the following:

Goals

G01 | Create a low-cost switch interface
G02 | Create an easy to build switch interface

Functional Requirements

F01 | Device must accept up to two 3.5 mm switch inputs
F02 | Device must output HID keystrokes to the connected device

Constraints

C01 | Device cannot use a custom PCB
C02 | Device cannot require soldering

Now that the device is further along in development, we can compare it with the goals, requirements and constraints.

Goals

- G01: The Shrub Hub has a unit cost of $27.19 CAD and a total cost of $33.01 CAD, compared to the Rocket Switch, which has a unit cost of $21 and a total cost of $45. This makes the Shrub Hub cheaper for a single unit build, and similar for a bulk build to the Rocket Switch, which is the MMC budget switch interface. This is a pass.
- G02: The Shrub Hub can be assembled with no soldering and only requires a screwdriver to assemble the Switch Adapter. This is a pass.

Functional Requirements

- F01: The Shrub Hub can connect to three 3.5 mm switch inputs. This is a pass
- F02: The Shrub Hub sends three sets of five HID keystrokes, as well as a set of five mouse clicks and five media control commands. This is a pass

Constraints

- C01: The device does not require a custom PCB. This is a pass
- C02: The device does not require soldering to assemble. This is a pass.

After reviewing the goals, requirements, and constraints set out in the beginning of the project, the Shrub Hub meets all of them

This section defines the verification and validation (V&V) activities required to confirm that the device meets its design requirements, user and stakeholder needs, and applicable safety and performance expectations.

- Verification ensures the design was built correctly according to specifications.
- Validation ensures the right design was built, meeting user needs in real-world use.

## Verification

### Verification Objective

Confirm that all design requirements have been met through objective evidence such as inspection, analysis, or testing.

### Verification Methods

Common verification methods include:

- Inspection: Visual or measurement confirmation (e.g., enclosure dimensions, solder joints).
- Analysis: Analytical confirmation (e.g., thermal calculations, firmware memory usage).
- Test: Functional testing under controlled conditions (e.g., switch response time).
- Demonstration: Simple operational proof (e.g., assembly demonstration).

### Verification Matrix

Requirement ID | Requirement | Verification ID | Verification Method | Acceptance Criteria | Result / Status (Pass/fail, comment?) | Evidence Reference (linking to results/data that showed we passed the requirement)
N/A | Shrub Hub enclosure must be printable on a high-end printer (Bambu P1S, Prusa Mk4) | V01a | Demonstration | The enclosure can be printed on a high end printer with text visible and all features functional | Pass
N/A | Shrub Hub enclosure must be printable on an older printer (Ender 3) | V01b | Demonstration | The enclosure can be printed on an older printer with text visible and all features functional | Pass
N/A | Switch Adapter enclosure must be printable on a high end printer (Bambu P1S, Prusa Mk4) | V02a | Demonstration | The enclosure can be printed on a high end printer with text visible and all features functional | Pass
N/A | Switch Adapter enclosure must be printable on an older printer (Ender 3) | V02b | Demonstration | The enclosure can be printed on an older printer with text visible and all features functional | Pass
N/A | Reset button must not get stuck in use when printed on a high end printer (Bambu P1S, Prusa Mk4) | V03a | Demonstration | When pressing the reset button on the assembled device, the lever arm should spring back and not remain pressed | Pass
N/A | Reset button must not get stuck when printed on an older printer (Ender 3) | V03b | Demonstration | When pressing the reset button on the assembled device, the lever arm should spring back and not remain pressed | Pass
N/A | The reset button must last 1000 presses | V04 | Test | The reset button should be able to be pressed a thousand times and still work without getting stuck. | Pass
N/A | The reset button arm should still work after 1 month | V05 | Demonstration | The reset arm should not creep enough to stop working after a month | Pass
N/A | The device must be able to be cleaned with a damp cloth. | V06 | Demonstration | The Shrub Hub can be cleaned with a damp cloth. | Pass
N/A | The light pipe should be installable with less than TBR and more than TBR grams of force | V07 | Test | The user should be able to install the light pipe with less than TBR and more than TBR grams of force
N/A | The Shrub Hub enclosure must last 25 snap fit cycles | V08 | Test | The enclosure should be able to be installed and removed 25 times without breaking | Pass
N/A | The Switch Adapter enclosure must last 50 snap fit cycles | V09 | Test | The enclosure should be able to be installed and removed 50 times without breaking | Pass
N/A | The Shrub Hub must withstand a 100 cm drop onto concrete | V10 | Test | The Shrub Hub should be dropped from 100 cm onto concrete and inspected for damage | Pass
N/A | The Shrub Hub with Switch Adapter must withstand a 100 cm drop onto concrete | V11 | Test | The Shrub Hub with Switch Adapter should be dropped from 100 cm onto concrete and inspected for damage | Pass
| With a single mono switch connected, the Shrub Hub should send the first input of the active mode | V12a | Demonstration | Connect a mono switch to the Shrub Hub, press it and monitor the output. | Pass
| With a single TRS switch connected, the Shrub Hub should send the first input of the active mode | V12b | Demonstration | Connect a TRS switch to the Shrub Hub, press it and monitor the output. | Pass
| Holding any switch for more than the mode change time should change the mode | V13 | Demonstration | Connect a switch to the Shrub Hub, press it for more than the mode change time and verify that no output is sent and the mode changes. | Pass
| A switch connected to the switch 1 port of the Switch adapter should send the first input of the active mode | V14a | Demonstration | Connect a switch to the Switch Adapter port 1, press it and monitor the output. | Pass
| A switch connected to the switch 2 port of the Switch adapter should send the second input of the active mode | V14b | Demonstration | Connect a switch to the Switch Adapter port 2, press it and monitor the output. | Pass
| A switch connected to the switch 3 port of the Switch adapter should send the third input of the active mode | V14c | Demonstration | Connect a switch to the Switch Adapter port 3, press it and monitor the output. | Pass
| A switch connected to the switch 1 port of the Switch adapter pressed at the same time as a switch connected to the switch 2 port should send the fourth input of the active mode | V14d | Demonstration | Connect a switch to the Switch Adapter port 1 and one to port 2, press them and monitor the output. | Pass
| A switch connected to the switch 3 port of the Switch adapter pressed at the same time as a switch connected to the switch 2 port should send the fifth input of the active mode | V14e | Demonstration | Connect a switch to the Switch Adapter port 3 and one to port 2, press them and monitor the output. | Pass
| A switch connected to the switch 1 port of the Switch adapter pressed at the same time as a switch connected to the switch 3 port should send the first input of the active mode | V14f | Demonstration | Connect a switch to the Switch Adapter port 1 and one to port 3, press them and monitor the output. | Pass
| When switches connected to all three switch ports are pressed at the same time, the device should send the first input of the active mode | V14g | Demonstration | Connect a switch to each Switch Adapter port, press them all at the same time and monitor the output. | Pass
| All outputs should match the outputs described in the User Guide output table | V15 | Demonstration | Test every mode and switch combination, monitor the outputs, and compare them to the ones on the table. | Pass
| The colour of the mode indicator should match the colours listed on the output table for the different modes. | V16 | Demonstration | Cycle through the modes and compare the colours to the ones on the table | Pass
N/A | The Shrub Hub should not send outputs when plugging in a switch | V17a | Demonstration | The Shrub Hub should be connected to a computer and a switch plugged in while outputs are monitored | Pass
N/A | The Shrub Hub should not send outputs when plugging in the Switch Adapter | V17b | Demonstration | The Shrub Hub should be connected to a computer and the Switch Adapter plugged in while outputs are monitored | Pass
N/A | The Shrub Hub should not send outputs when plugging a switch into the Switch Adapter | V17c | Demonstration | The Shrub Hub with Switch Adapter should be connected to a computer and a switch plugged in while outputs are monitored | Pass
N/A | The cables of the Switch Adapter should not come loose if a switch is improperly unplugged. | V18 | Demonstration | A switch should be connected to the Switch Adapter and unplugged with one hand pulling on the switch plug and the other holding the enclosure of the switch adapter. | Pass
N/A | The cables of the Switch Adapter should not come loose if a switch is improperly unplugged after being installed for a month. | V19 | Test | A switch should be connected to the Switch Adapter and unplugged with one hand pulling on the switch plug and the other holding the enclosure of the switch adapter. This test should be performed on a Switch adapter that has been assembled for a month. | Pass
N/A | The Switch Adapter should not come loose if a switch is improperly unplugged. | V20 | Demonstration | A switch should be connected to the Switch Adapter while plugged into the Shrub Hub and unplugged with one hand pulling on the switch plug and the other holding the enclosure of the Shrub Hub | Pass
N/A | The timing of the device should not drift more that 10 percent in a week. | V21 | Test | A test program should be loaded onto the microcontroller that blinks the microcontroller every 10 seconds. This program should be left to run for a week and the timing of the blinks measured. | Pass
N/A | The device should work equally as well on Windows, Linux, Android, iOS and MacOS | V22 | Demonstration | The device should be used on each of the operating systems to be tested and send the required outputs. | Tentative pass
N/A | A user should be able to plug a USB drive into the port next to the device. | V23 | Demonstration | The Shrub hub with Switch Adapter should be plugged into a USB port and several USB devices plugged into the port next to it. | Tentative Pass | Can plug the USB flash drives next to the shrub hub, but only thin flash drives can be plugged in next to it when the switch adapter is connected
N/A | The Shrub Hub Enclosure should work with all TRRS Trinkey Boards | V24 | Demonstration | The first 10 Shrub Hubs built by MMC should be inspected for fit of the enclosure and that the lid fully snaps into place.
N/A | Shrub Hub enclosure should fit the TRRS Trinkey PCB even when printed on an older printer (Ender 3) | V25 | Demonstration | The TRRS Trinkey should fit into the Shrub Hub enclosure when it is printed on an older printer | Pass
| Can the Switch Adapter be constructed with different cables | V26 | Demonstration | The Switch Adapter should be attempted to be constructed using a variety of cables. | Fail | Larger cables do not work with the cable retention arms

### Verification Summary

## Validation

### Validation Objective

Confirm that the final design meets user and stakeholder needs in its intended context of use.

### Validation Questions

The following list of questions was used for brainstorming what to ask the users on the Microsoft Form.

- External Build Validation
  - Can a user without a technical background build the device following the Maker Guide?
  - Can a user without a technical background modify the outputs?
  - Can a user with a technical background modify the outputs?
- Shipping Validation
  - Does the finished device fit in letter mail?
  - Does the finished device fit in oversized letter mail?
  - Does the device require padding to ship safely?
- User Validation
  - Can a user set up the device following the user guide

#### User Validation

### Validation Matrix

Validation ID | Validation Objective | Participant(s) | Procedure | Acceptance Criteria | Result / Comment

End-user Validation
Val01 | Ensure that a user can set up the device using the User Guide | | Provide prototype for participants to test. | Testers verify that they can follow the user guide and test the device
Val02 | Ensure that a primary user can send single switch outputs | | Provide prototype for participants to test. | Primary user uses a connected assistive switch to send an output
Val03 | Ensure that a primary user can send two switch outputs | | Provide prototype for participants to test. | Primary user uses two assistive switches to send a chorded output
Val04 | Ensure that a primary user can change the mode of the device | | Provide prototype for participants to test. | User holds a button for more than the mode change time and changes the mode of the device.
Val05 | Determine appropriate default mode change time | | Provide prototype for participants to test. | Testing participants provide appropriate default mode change times.
Val06 | Determine if users would be better served by a different default set of outputs | | Provide prototype for participants to test. | Testing participants provide appropriate default outputs.
Val07 | Ensure the device is an acceptable size. | | Provide prototype for participants to test. | Testers verify the Shrub Hub is an acceptable size with and without the Switch Adapter.
Val08 | Ensure the device is an acceptable weight. | | Provide prototype for participants to test. | Testers verify the Shrub Hub is an acceptable weight with and without the Switch Adapter.
Val09 | Ensure the User Guide is not missing information. | | Provide participants with the User Guide to read through and reference when testing the Shrub Hub. | Secondary users provide feedback on what information should be added to the User Guide.
Val10 | Ensure the User Guide is written clearly. | | Provide participants with the User Guide to read through and reference when testing the Shrub Hub. | Secondary users provide feedback on how to make the User Guide clearer.
Val11 | Secondary user is able to change the outputs of the device | | Provide participants with the User Guide and Shrub Hub. | Secondary user is able to modify the code of the Shrub Hub to change the outputs

Volunteer Maker Validation
Val12 | Ensure a maker without a technical background can build the device. | | Have volunteer maker build the device | Volunteer maker is able to build the Shrub Hub following the maker guide
Val13 | Ensure the device can fit through a Canada Post oversized letter mail slot | Brad | Have volunteer maker mail the device | Maker is able to fit the packaged device through an oversized Canada Post mail slot | Pass
Val14 | Ensure that the device does not get damaged in the mail. | | Have volunteer maker mail the device | Maker is able to mail the device and it arrives without damage

### Validation Summary

# Design Transfer

## Media

MMC Library Main Photo

- Using photo of Hub w/out Adapter✓

MMC Library Listing Photos

- Standalone Hub Photo ✓
- Hub w/ Adapter Photo ✓
- Attached to Laptop Photo ✓
- Attached to Phone Photo ✓
- With USB-A extender? Photo✓
- LipSync -style connection diagram ✓ ✓
- Output functionality
  - (table) ✓
- Line-art icon ✓ ✓

## Licensing

Hardware: CERN-OHL-W v2

Software: GNU General Public License v3.0 (GPL-3.0).

Documentation: CC BY-SA 4.0

## Attribution

The device was designed by Neil Squire Society.

The Shrub Hub is built using the following commercially available open-source hardware components:

- Adafruit TRRS Trinkey - USB Key for Assistive Technology (https://www.adafruit.com/product/5954). The PCB design is available under a CC-BY-SA 3.0 license at https://github.com/adafruit/Adafruit-TRRS-Trinkey-PCB. It is certified as open hardware with the Open Source Hardware Association (OSHWA) as US002639 (https://certification.oshwa.org/us002639.html).

The Shrub Hub is programmed in CircuitPython (https://circuitpython.org/) using the Mu Python Editor (https://codewith.mu/)

### Contributors

- Brad Wellington. Shrub Hub Enclosure, firmware, documentation. Neil Squire Society / Makers Making Change.
- Bill Binko. TRRS Trinkey PCB design and Learning Guide. ATMakers.org.
- Chris Young. TRRS Trinkey PCB Design. ATMakers.org.
- Eric Chau. Testing. Neil Squire Society / Solutions.
- Jake McIvor. Documentation, testing. Neil Squire Society / Makers Making Change.
- Limor Fried. TRRS Trinkey PCB Design. Adafruit (https://www.adafruit.com/).
- Liz Clark. TRRS Trinkey Learning Guide. Adafruit (https://www.adafruit.com/).
- Jody Dickerson. Testing. Neil Squire Society / Solutions.
- Josie Versloot. Testing. Neil Squire Society / Makers Making Change.
- Stephan Dobri. Testing. Neil Squire Society / Makers Making Change.

## Delivery / Shipping Information

| Value | Notes
Total Shipping Mass | TBC grams
Total Shipping Envelope | TBC mm x TBC mm x TBC mm

# Opportunities for Improvement

### Functionality

- Investigate mouse cursor control
- Investigate mouse scroll wheel modes
- Investigate utility of mode changes being controllable by the primary user
  - Changing to something like the Ivy mode change where it changes mode if it is plugged in while a certain button is held would allow the code to be changed to allow holding inputs/activating inputs on button press

### Enclosure

- Height of USB connector varies from board to board, causing minor fit issues between boards
- Add feature to provide for mounting?

### Electrical Components

- Better documentation on how to determine which input goes to which ring on the TRRS/which switch input
- Examine options for a better method of labeling the switch inputs than the rings of silver sharpie.

### Code Structure / Function

- The main improvement that needs to be made is the addition of a settings mode like in the Rocket Switch.
- The mode could be saved so it does not need to be reselected after unplugging the device.
- Detect when only the stereo splitter is in use and disable the third switch input so it is not constantly pressing
  - This could be extended to disable any input that is held for too long and maybe send an error?
  - Detect when a cable is plugged/unplugged to allow it to scan for shorted inputs and
- Detect when jack is connected?
- How do we make it easier for a user to reduce the number of operating modes?
- How do we make it easier for operating mode changes to be disabled?
- How do we make it easier to enable / disable chording entries?
- Adding a gaming mode
- Adding a way to allow for sending keystrokes on a button press/allowing for keystrokes to be held

# Appendix

## Appendix A – Verification Test

f

© 2026 by Neil Squire. This work is licensed under the CC BY SA 4.0 License: http://creativecommons.org/licenses/by-sa/4.0 Files available at https://github.com/makersmakingchange/Shrub-Hub Page 1 of 1

V1.0 | January 2026 Shrub Hub Design Rationale

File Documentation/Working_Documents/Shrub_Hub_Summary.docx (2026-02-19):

# Overview

The Device Summary is intended to be a detailed summary of the device, product and maker information for the Shrub Hub, making it easier to add to the Makers Making Change website. It is intended for anyone who will view the device listing.

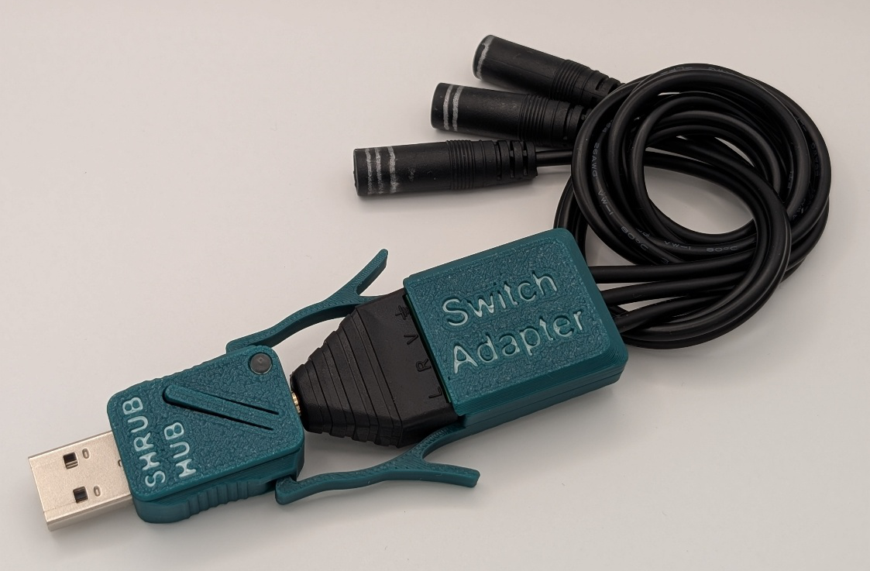
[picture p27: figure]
Fully assembled Shrub Hub and 3-to-1 Switch Adapter.
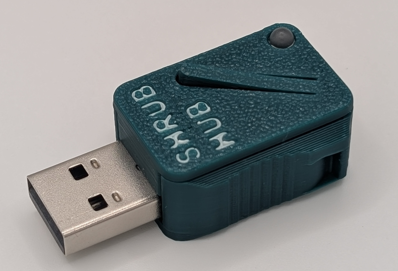
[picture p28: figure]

# Product Information

## Product Name

Shrub Hub

## Device Category

Mark any relevant categories with an “X”:

| Adapted Toys
| Aids for Daily Living (ADL)
| Assistive Switches
| Communication Aids (AAC)
X | Computer Access
| Environmental Controls
| Gaming
| Keyguard
| Kits
| LipSyncs
| Mounting
| Recreation and Leisure
| Seating and Positioning
| Switch Interfaces
| Writing Aids

## User Value Statement

The Shrub Hub allows users who are unable to operate a digital device such as a computer to send keystrokes to navigate webpages, switch scan, send mouse clicks, and control device audio and other media.

## Designer

Neil Squire Society

# Device Information

## Overview

The Shrub Hub is a low-cost digital switch interface that takes up to three assistive switch inputs and can output up to five keystrokes to the connected digital device.

## Disability Type

Select one or more disability types and mark with an “X”:

X | Agility / Dexterity
| Arthritis
| Cognitive
| Hearing
| Mobility
| Pain
| SCI
| Vision
| Other

## Disability Type Description

The Shrub Hub is intended for users who cannot use digital devices and need a digital switch interface to control the device using assistive switches.

## How To Use

The Shrub Hub is connected to up to three 3.5mm assistive switches, and then plugged into a computer or other digital device like a USB flash drive. If only using one switch, the Shrub Hub can be used without the switch adapter, and the switch can be plugged directly into the Shrub Hub. Each switch can be pressed to send a different keystroke, or multiple switches can be pressed at the same time to send a different keystroke than any of the individual buttons. There are five different modes that each have their own unique sets of outputs.

## Estimated Cost

The estimated material cost of the device for a single build:

| $0 - $10
| $11 - $25
x | $26 - $50
| $51 - $100
| $101 - $250
| $250+

## Attribution

The device was designed by Neil Squire Society.

The Shrub Hub is built using the following commercially available open-source hardware components:

- Adafruit TRRS Trinkey - USB Key for Assistive Technology (https://www.adafruit.com/product/5954). The PCB design is available under a CC-BY-SA 3.0 license at https://github.com/adafruit/Adafruit-TRRS-Trinkey-PCB. It is certified as open hardware with the Open Source Hardware Association (OSHWA) as US002639 (https://certification.oshwa.org/us002639.html).

The Shrub Hub is programmed in CircuitPython (https://circuitpython.org/) using the Mu Python Editor (https://codewith.mu/)

### Contributors

Designers:

- Shrub Hub:
  - Brad Wellington, Neil Squire Society / Makers Making Change.
- Original TRRS Switch Control Device:
  - Chris Young
  - Bill Binko

Testers:

- Jake McIvor, Neil Squire Society / Makers Making Change.
- Josie Versloot, Neil Squire Society / Makers Making Change.
- Stephan Dobri, Neil Squire Society / Makers Making Change.
- Jody Dickerson, Neil Squire Society / Solutions
- Eric Chau, Neil Squire Society / Solutions

# Maker Information

## Project Skills

Mark the required project skills with an “X”:

X | 3D Printing
| Custom PCB
| Electronics
| Laser Cutting
| Mechanics
X | Software
| Soldering
| Woodworking
| Other

## Skills Description

This device is specifically intended to be easy to build. The only skill needed is being able to 3D print and drag and drop files. There is optional customization that can be done if the maker is comfortable with minor software changes.

## Tools Needed

X | 3D Printer
X | Common Hand Tools
| Common Power Tools
| Laser Cutter
| Soldering Iron
| Specialized Tooling

## Print time (hrs)

0.1667

## Assembly time (hrs)

0.2

## Build Instructions

This build is mainly snapping together a 3D printed enclosure. The splitter build involves stripping wires and screwing them into a terminal, but the build involves no soldering or custom PCBs.

## Download Link

https://github.com/makersmakingchange/Shrub-Hub/archive/refs/heads/main.zip

## Project Link

https://github.com/makersmakingchange/Shrub-Hub

# License

## License

Hardware: CERN-OHL-W v2

Software: GNU General Public License v3.0 (GPL-3.0).

Documentation: CERN-OHL-W v2

© 2026 by Neil Squire. This work is licensed under the CC BY SA 4.0 License: http://creativecommons.org/licenses/by-sa/4.0 Page 1 of 2

V1.0 | January 2026 Shrub Hub Summary

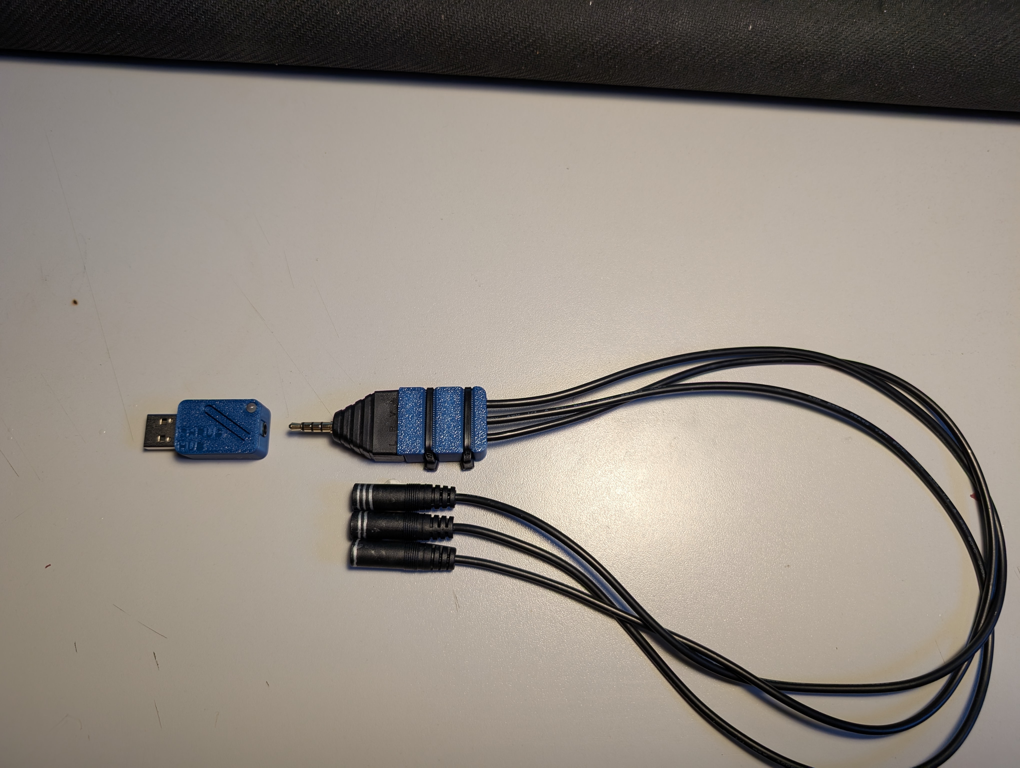
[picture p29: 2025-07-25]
Documentation/Working_Documents/Assets/Trinkey and splitter.jpg

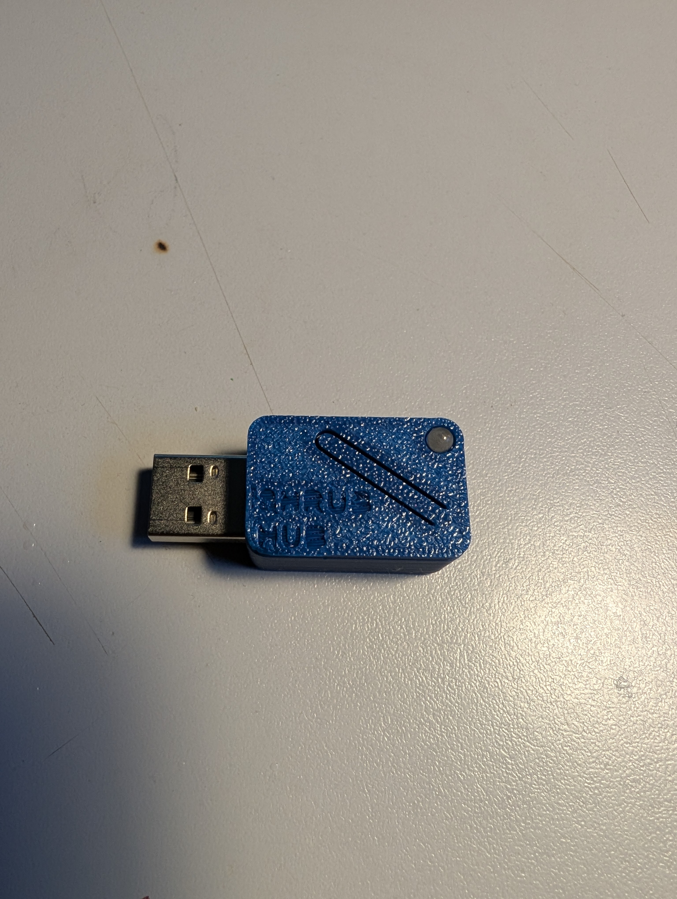
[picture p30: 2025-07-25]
Documentation/Working_Documents/Assets/Trinkey Enclosure.jpg

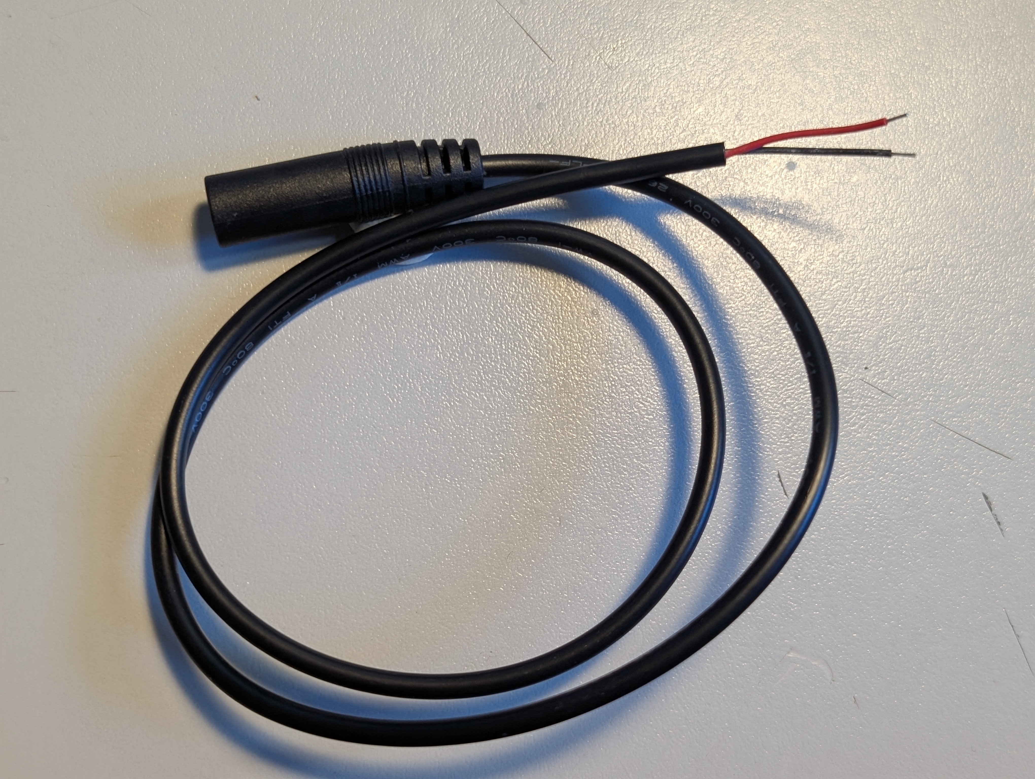
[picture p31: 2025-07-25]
Documentation/Working_Documents/Assets/Mono_Cable.jpg

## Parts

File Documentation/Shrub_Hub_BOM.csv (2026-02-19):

Device: | Shrub Hub
Version: | V1.0
Last Updated: | 2026-01-16
 |  |  |  |  |  |  |  | Total filament (g) |  | Unit Cost | Total Estimated Cost
 |  |  |  |  |  |  |  | 10 |  | $35.19 | $52.46
ID | Commercial Parts |  |  |  |  |  |  |  |  | $34.94 | $52.21
 | Part | Description | MPN | Manufacturer | Supplier | QTY / Device | QTY / PKG | PKGs | $/ PKG | $ / Device | Total Estimated Cost |  | Link
A01 | Adafruit TRRS Trinkey | Trinkey Microcontroller | 5954 | Adafruit | Digikey | 1 | 1 | 1 | $14.50 | $14.50 | $14.50 |  | https://www.digikey.ca/en/products/detail/adafruit-industries-llc/5954/24614902
A04 | Light Pipe | Transparent Light Pipe | 51513030250F | Dialight | Digikey | 1 | 1 | 1 | $1.57 | $1.57 | $1.57 |  | https://www.digikey.ca/en/products/detail/dialight/51513030250F/4965201
B01 | TRRS Terminal | 3.5 mm TRRS Terminal Block |  |  | Amazon | 1 | 2 | 1 | $6.58 | $3.29 | $6.58 |  | https://amazon.ca/dp/B0B4PD2R5G
B02 | Mono Cable, Female, 3.5 mm, 0.5 m | Pre-Stripped 3.5 mm Mono Cable w/ Female Plug |  |  | Amazon | 3 | 4 | 1 | $10.11 | $7.58 | $10.11 |  | https://amazon.ca/dp/B0BZWK7PLP
 | Shipping - Digikey | Digikey Shipping for <$100 CAD Order |  |  | Digikey | 1 | 1 | 1 | $8.00 | $8.00 | $8.00
 | Shipping - Amazon |  |  |  | Amazon | 1 | 1 | 1 | 0 | 0 | $-
 | 3D Printed Parts |  |  |  |  |  |  | 12 |  | $0.25 | $0.25
 | Part | Description | Filament Type | Filament | Color | QTY / Device | Mass (g) / Part | Total Mass | $ / kg | $ / Device | Total Estimated Cost |  | Link
A02 | Shrub_Hub_Base.stl | Bottom of enclosure | PLA |  | Any | 1 | 3 | 3 | $25.00 | $0.08 | $0.08
A03 | Shrub_Hub_Lid.stl | Top of enclosure | PLA |  | Any | 1 | 1 | 1 | $25.00 | $0.03 | $0.03
B03 | Switch_Adapter_Base.stl | Bottom of Switch Adapter enclosure | PLA |  | Any | 1 | 4 | 4 | $25.00 | $0.10 | $0.10
B04 | Switch_Adatper_Lid.stl | Top of Switch Adapter enclosure | PLA |  | Any | 1 | 2 | 3 | $25.00 | $0.05 | $0.05
 | Accessories
 | Part | Description |  | Manufacturer | Supplier | QTY / Device | QTY / PKG | PKGs | $/ PKG | $ / Device | Total Estimated Cost |  | Example Link
 | USB-A Extender | USB A Male - USB A Female Extender |  | Cable Matters | Amazon | 1 | 1 | 1 | $10.95 | $10.95 | $10.95 |  | https://www.amazon.ca/Cable-Matters-Extension-Black-Feet/dp/B00C7S2FRE
 | Tools
 | Tool | Description |  | Manufacturer | Supplier |  |  |  |  |  |  |  | Example Link
T01 | Wire Strippers | Recommended - Cable stripping
T02 | Screwdriver, Phillips, Small (PH1) | Required
T03 | Silver Sharpies | Recommended - Cable marking
 | Alternatives
 | Part | Description |  | Manufacturer | Supplier | QTY / Device | QTY / PKG | PKGs | $/ PKG | $ / Device | Total Estimated Cost |  | Link
A01 | Adafruit TRRS Trinkey |  |  | Adafruit | Mouser | 1 | 1 | 1 | $15.17 | $15.17 | $15.17 |  | https://www.mouser.ca/ProductDetail/Adafruit/5954?qs=wT7LY0lnAe2DcfdqLcHAgA%3D%3D
A01 | Adafruit TRRS Trinkey |  |  | Adafruit | Adafruit | 1 | 1 | 1 | $13.62 | $13.62 | $13.62 | Ships from US | https://www.adafruit.com/product/5954
B01 | TRRS Terminal |  |  | GLARKS | Amazon | 1 | 8 | 1 | $14.93 | $14.93 | $14.93 |  | https://amazon.ca/dp/B07KF8SRC3
B02 | Mono Cable, 3.5 mm, 1 ft or less |  |  | Fancasee | Amazon | 3 | 10 | 1 | $20.22 | $20.22 | $20.22 |  | https://amazon.ca/dp/B082VW97TT
B02 | Mono Cable, 3.5 mm, 1 ft or less |  |  | Adafruit | Digikey | 3 | 1 | 3 | $2.84 | $8.52 | $8.52 |  | https://www.digikey.ca/en/products/detail/adafruit-industries-llc/4182/10230000

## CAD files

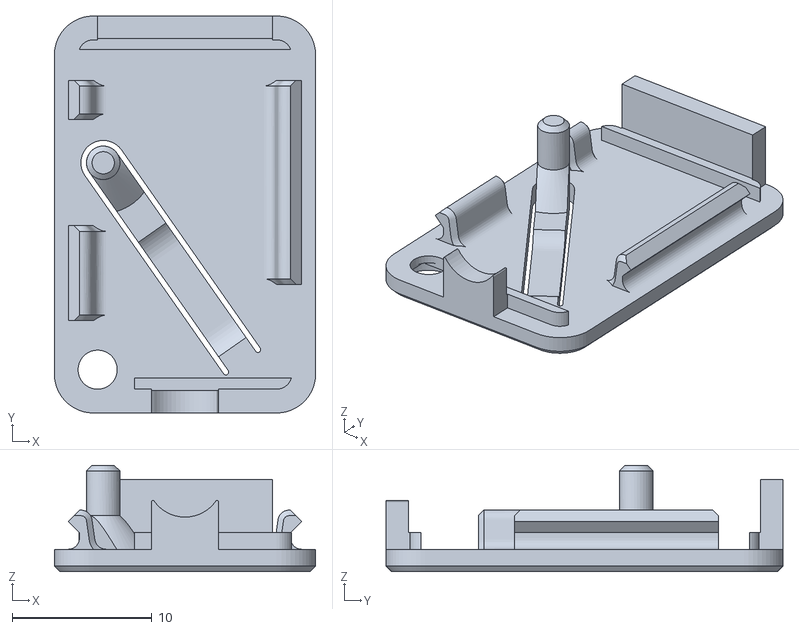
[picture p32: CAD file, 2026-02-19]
Build_Files/3D_Printing_Files/Shrub_Hub_Lid.stl
18.7 x 28.4 x 7.60

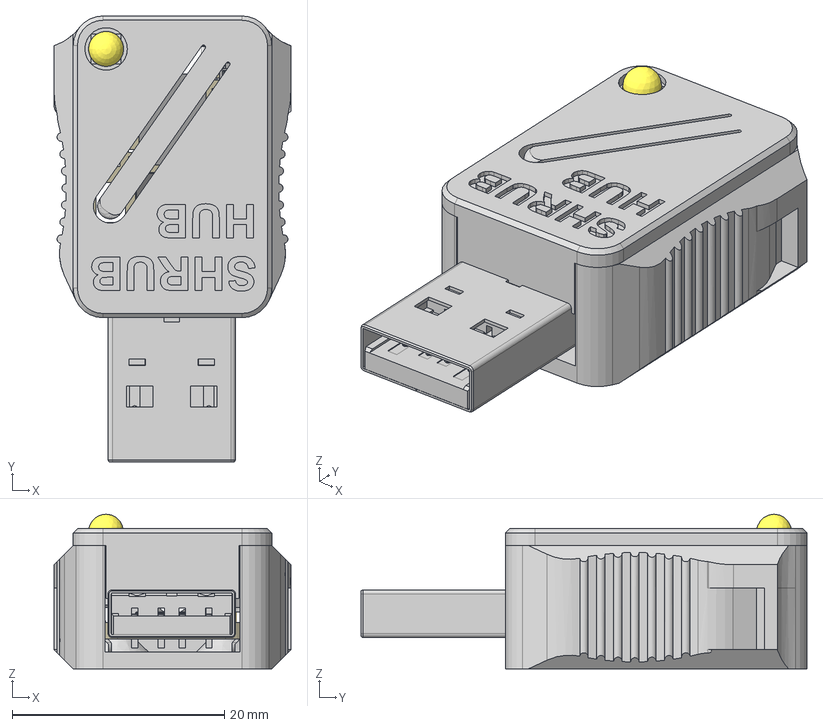
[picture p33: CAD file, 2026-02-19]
Design_Files/CAD_Design_Files/Step/Shrub_Hub.step
22.3 x 42.0 x 14.6 mm
Base
Lid
Board
USB_A-UGO4DD
10uF x 2
RKB
ATSAMD21E
1uF x 2
AP2127K-3.3
WS2812B_SK6805_1515
TRRS_2SWITCH_PJ332A
STEMMA_I2C_QTRA
Light Pipe

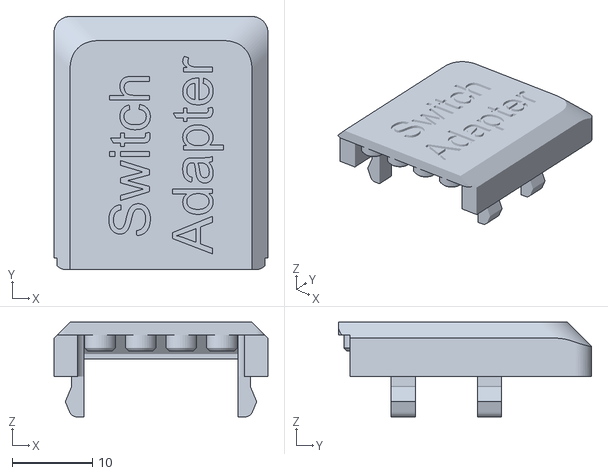
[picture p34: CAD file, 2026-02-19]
Build_Files/3D_Printing_Files/Switch_Adapter_Lid.stl
26.6 x 31.4 x 11.8

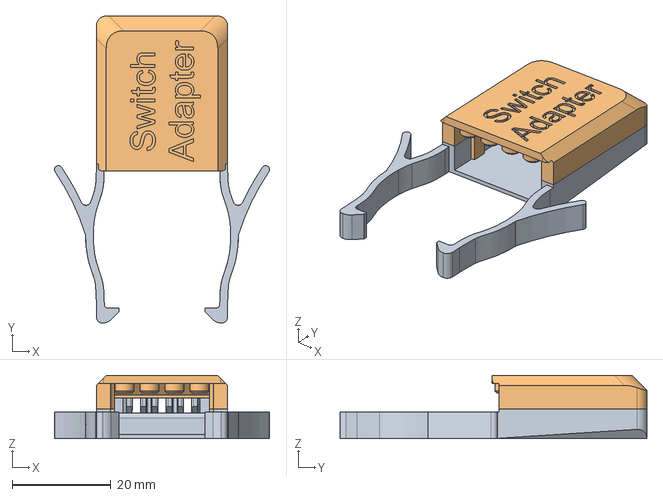
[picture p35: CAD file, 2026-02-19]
Design_Files/CAD_Design_Files/Step/Shrub_Hub_Switch_Adapter.step
43.6 x 62.2 x 12.8 mm
Base
Lid

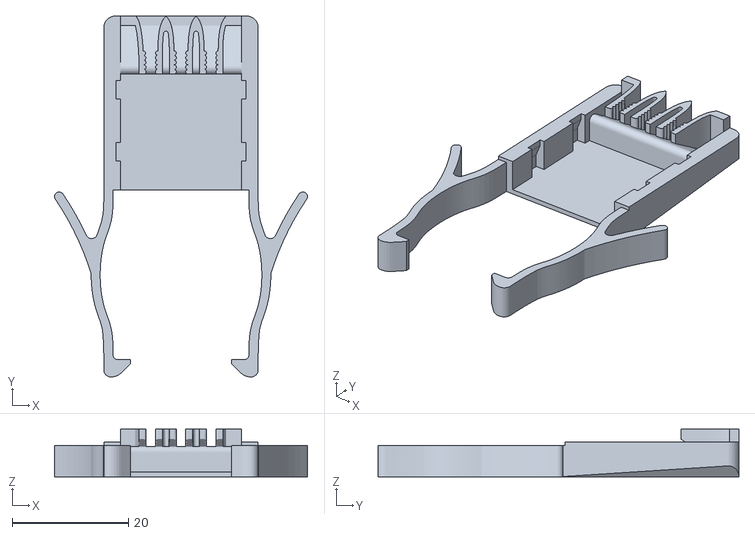
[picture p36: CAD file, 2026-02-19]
Build_Files/3D_Printing_Files/Switch_Adapter_Base.stl
43.6 x 62.2 x 8.20

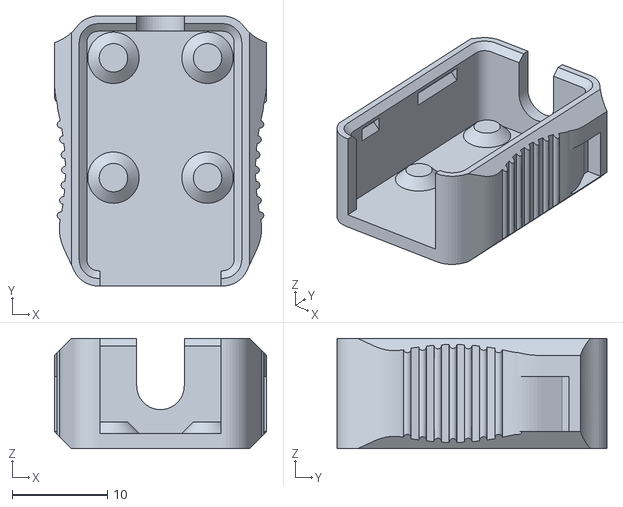
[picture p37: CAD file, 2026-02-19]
Build_Files/3D_Printing_Files/Shrub_Hub_Body.stl
22.3 x 28.4 x 11.6

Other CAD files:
Design_Files/CAD_Design_Files/Fusion/Shrub_Hub_Enclosure.f3z
Design_Files/CAD_Design_Files/Fusion/Shrub_Hub_Switch_Adapter.f3d

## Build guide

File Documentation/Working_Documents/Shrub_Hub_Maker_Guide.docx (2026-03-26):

# Overview

This document contains the necessary information to build the Shrub Hub, a low cost, easy to build digital switch interface.

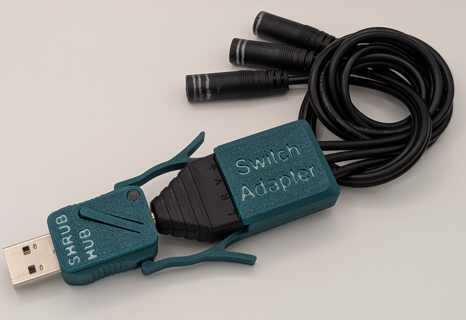
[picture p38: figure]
Completed Shrub Hub and 3-to-1 Switch Adapter.

Contents

# Maker Checklist

This list provides an overview of the steps required to build and deliver the Shrub Hub.

## Maker To Do List

- Read through the Maker Guide to become familiar with required components, tools, supplies, safety gear, and overall assembly steps.
- Talk to the User about how many switches they want to use
  - The Switch Adapter is only needed for 2 to 3 switches, if the User only wants 1 switch, you do not need to build the adapter
- Talk to the User about customization options
  - Colour of printed enclosure
  - How they would like to receive the “User Guide” (PDF or physical copy)
  - If they need the Switch Adapter, how long do they want the cables?
  - Do they need a USB extender?
  - Do they need the outputs of the device to be changed?
- Order hardware components
- Gather tools, supplies, and safety equipment.
- Assemble the device
- Flash firmware to Shrub Hub
- Test the Shrub Hub
- Print “User Guide” (if the User would like a physical copy)

## Items to Give to User

- Shrub Hub
- Switch Adapter (if required)
- “User Guide”

## Component Sourcing Notes

The 3-to-1 Switch Adapter is designed for mono audio cables with an outer diameter of 3 mm like the ones specified in the Bill of Materials. Cables with larger diameters may not work and may cause the enclosure to break.

The 3-to-1 Switch Adapter is designed for the TRRS terminal block sourced from Amazon. A similar part is available from Adafruit, but is too small and will not fit within the enclosure.

# Tool List

## Tools / Equipment

Tool ID | Description | Required / Recommended | Notes
T01 | Wire Strippers | Recommended | Stripping mono cable wires.
T02 | Small Phillips Screwdriver | Required | Operating TRRS terminal screws
T03 | Silver Sharpie® Marker | Recommended | Marking each cable

# Customization Guide

The device can be printed in the user’s desired colour.

The device outputs can be changed to better suit the user’s needs

# 3D Printing Guide

The device was originally printed on a Bambu P1S using BambuStudio slicer.

## 3D Printing Summary

Metrics | Single Unit
Total Print Time (hour:min) | 0:32
Total Number of Components | 4
Typical Total Mass (g) | 11
Typical Number of Print Setups | 1

## 3D Printing Settings

Note that the 3D printing material should be assumed to be PLA unless otherwise noted in the table below.

Print File Name | Qty | Total Print Time (hr:min) | Mass (g) | Infill (%) | Support(Y/N) | Layer Height/ Nozzle Diameter(mm) | Notes
Shrub Hub Base.stl | 1 | 0:06 | 3 | 20 | N | 0.2/0.4
Shrub Hub Lid.stl | 1 | 0:05 | 1 | 20 | N | 0.2/0.4
Switch Adapter Base.stl | 1 | 0:08 | 4 | 20 | N | 0.2/0.4
Switch Adapter Top.stl | 1 | 0:06 | 3 | 20 | N | 0.2/0.4

## Post-Processing

Inspect the 3D printed parts for any printing defects, sharp edges, or burrs. Sharp edges and burrs can be removed with sanding or deburring tools.

## Examples of Quality Prints

Compare your 3D prints to the images here. If there are significant differences, you may need to reprint the part.

Shrub Hub 3D Prints

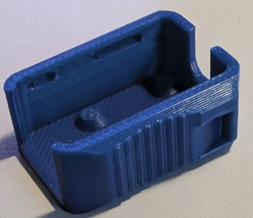
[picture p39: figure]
A quality print example of the Shrub Hub Base
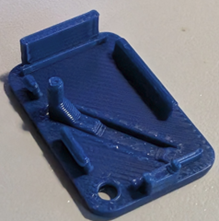
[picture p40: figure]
A quality print example of the Shrub Hub Lid
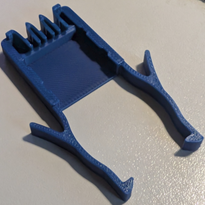
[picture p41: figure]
A quality print example of the Switch Adapter Base

Shrub Hub Base | Shrub Hub Lid | Switch Adapter Base

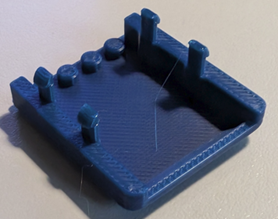
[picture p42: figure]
A quality print example of the Switch Adapter Lid

Switch Adapter Top

# Maker Component List

Part A: Shrub Hub Components

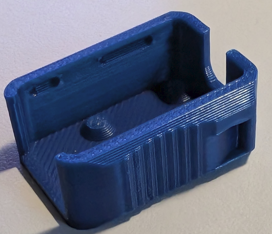
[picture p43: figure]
Base of the shrub hub printed in dark blue on a grey background
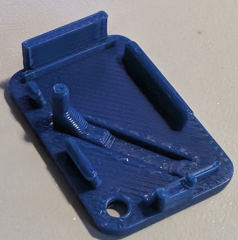
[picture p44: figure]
Lid of the shrub hub printed in dark blue on a grey background

A01 | TRRS Trinkey | | QTY: 1 | A02 | | Shrub Hub Base | QTY: 1 | A03 | | Shrub Hub Lid | QTY: 1
A04 | Light Pipe | QTY: 1

Part B: 3-to-1 Switch Adapter Components

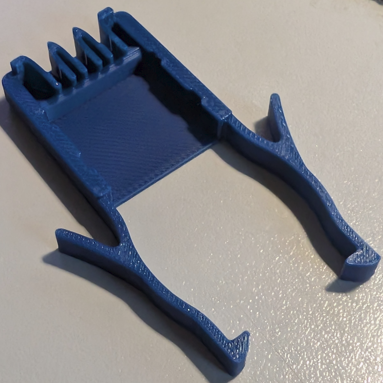
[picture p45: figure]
Base of the TRRS to three mono cable adapter printed in dark blue on a grey background

B01 | TRRS Terminal | QTY: 1 | B02 | Female Mono Cable | QTY: 3 | B03 | Switch Adapter Base | QTY: 1

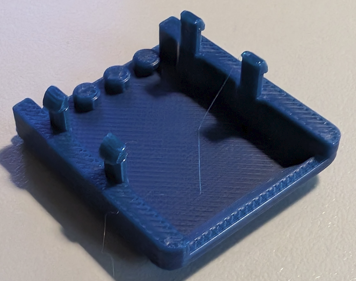
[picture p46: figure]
Lid of the TRRS to three mono cable adapter printed in dark blue on a grey background

B04 | Switch Adapter Top | QTY: 1

# Assembly Guide

## Part A: Assemble the Shrub Hub

### Part A: Required Tools and Supplies

- None

### Part A: Shrub Hub Assembly Steps

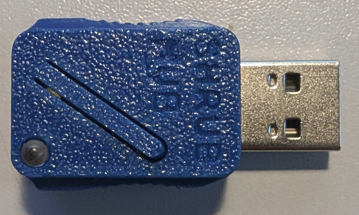
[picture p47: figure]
The trinkey fully installed in the enclosure on a grey background

#### Step A-01: Insert the light pipe into the Shrub Hub Lid

Take the light pipe (A04) and press it into the hole on the Shrub Hub Lid (A03).

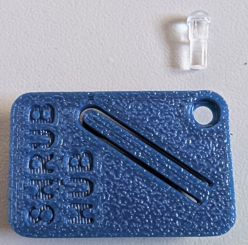
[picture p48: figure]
The trinkey enclosure top printed in blue on a grey background with a light pipe lying beside it
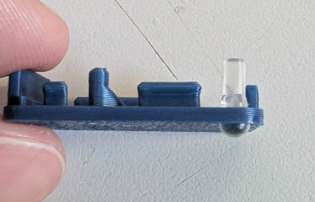
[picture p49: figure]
A side view of the trinkey lid with the light pipe installed in place

#### Step A-02: Attach the enclosure to the Trinkey

Place the TRRS Trinkey (A01) into the Shrub Hub Base (A02), then snap the Shrub Hub Lid (A03) on top of it to lock the Trinkey in place.

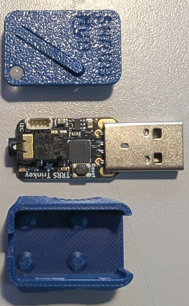
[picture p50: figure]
The trrs trinkey with the enclosure base below it and the enclosure top above it
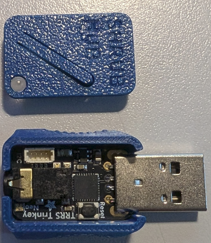
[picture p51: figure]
The trinkey sitting in the base with the lid above it
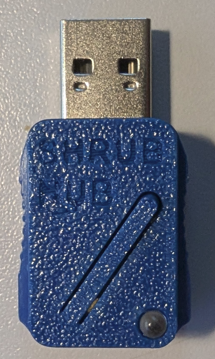
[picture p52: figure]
The trinkey fully installed in the enclosure on a grey background

## Part B: Assemble the Cable Adapter

### Part B: Required Tools and Supplies

- Small Phillips Screwdriver
- Wire Strippers
- Silver Sharpie® Marker

### Part B: Cable Adapter Assembly Steps

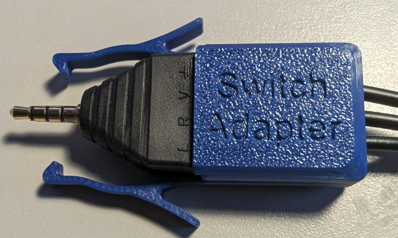
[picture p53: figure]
The fully assembled switch adapter

#### Step B-01: Strip the mono cables

Using wire strippers (T01), strip the ends on each mono cable (B02) so there is 1 cm of wire exposed. The wires do come pre stripped, but having slightly more wire available makes the next step easier. If the user wants a shorter cable, trim the entire cable shorter before exposing the wires and stripping the ends.

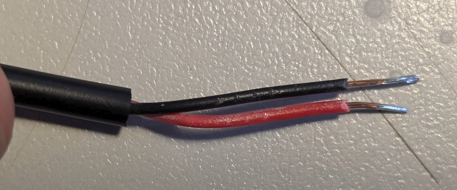
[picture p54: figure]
A close up of the stripped mono cable with an extra 5 mm of insulation removed on a grey background

#### Step B-02: Connect the Mono Cables to the TRRS Terminal Jack

Using the Small Phillips Screwdriver (T02), open the terminals on the TRRS Terminal Jack (B01). Put the black wires from all three of the stripped mono cables into the terminal marked L and then tighten the terminal to lock all the wires in place. Take the red wire from each of the mono cables, and attach one to each of the remaining terminals, one to R, one to V, and one to the ground (arrow shaped mark).

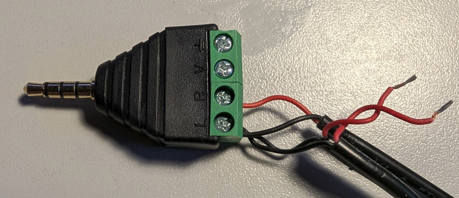
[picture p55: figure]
A picture of the TRRS Terminal splitter with a wire connected to the L and R terminals.
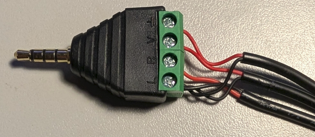
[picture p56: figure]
A picture of the TRRS Terminal splitter with a wire connected to every terminal, and three wires connected to the L terminal

#### Step B-03: Mark the Mono Cable connectors

Using a silver Sharpie® marker (T03) or other marking device, label the cable plug for Switch 1, Switch 2, and Switch 3. Switch 1 is the one with the red wire connecting to the V terminal, Switch 2 connects to the R terminal, and Switch 3 connects to the ground terminal.

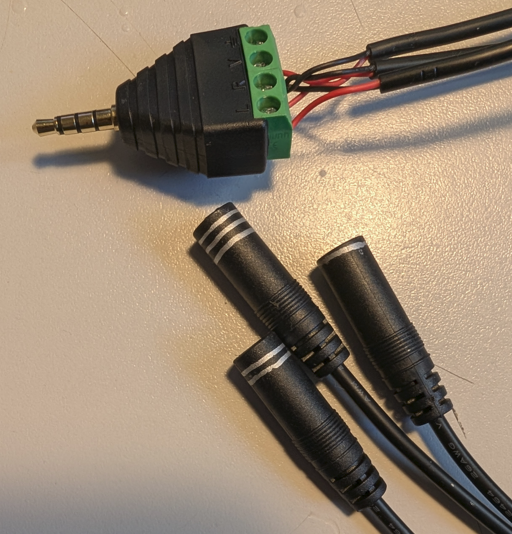
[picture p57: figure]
A close up of the female mono cable ports on the terminal splitter with silver sharpie marking the one, two, and three port

#### Step B-04: Assemble the Switch Adapter Base

Take the Switch Adapter Base (B03) and place the TRRS splitter jack between the gripping arms of the Switch Adapter Base. Press the mono cable wires one by one into the retention slots, pushing until they are at the bottom of the slot. Leave some slack in the wires that are screwed into the terminal block.

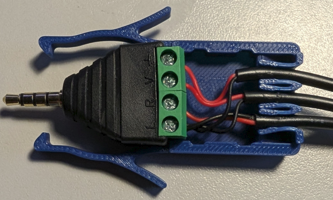
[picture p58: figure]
An assembled TRRS jack placed in the base of the switch adapter with cables pressed in place

#### Step B-05: Close the Switch Adapter

Take the Switch Adapter Lid (B04) and press it into the base, aligning the four tabs with the slots on the base, and the four posts with the screw holes on the terminal block.

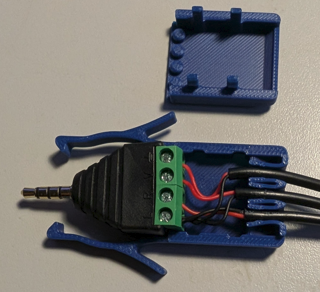
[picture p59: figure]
The partially assembles switch adapter with the lid sitting next to is
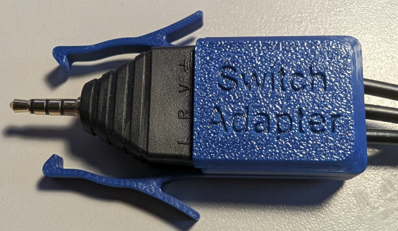
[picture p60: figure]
The fully assembled switch adapter

## Part C: Flashing Firmware to Shrub Hub

### Part C: Required Tools and Supplies

- Computer that can open a USB flash drive

### Part C: Programming Steps

#### Step C-01: Connect the Shrub Hub to the Computer

Plug the Shrub Hub into a USB port on the computer. If the computer does not have a USB-A port, an adapter will be required to connect the Hub to the computer.

#### Step C-02: Install CircuitPython

1. Open File Explorer
2. Double press the reset button on the Shrub Hub. A drive called TRINKEYBOOT should appear, similar to plugging in a USB flash drive.
3. Open the folder in the /Build_Files/Firmware_Files/Bootloader directory in the project files for the Shrub Hub.
4. Drag and drop the provided .uf2 file into the drive. It should then disappear, and a drive called CIRCUITPY should appear.

#### Step C-03: Add the library files

1. Open the lib folder in the /Build_Files/Firmware_Files/Shrub Hub Firmware directory
2. Copy all the files found there.
3. Paste them into the lib folder in the CIRCUITPY drive

Note: If you downloaded individual files instead of the entire project repository, it is recommended to download the repository for this step. Copying the contents of the folder onto the Shrub Hub is much easier than downloading each file individually and recreating the file structure yourself. The repository can be downloaded from the device listing on the MMC website or by clicking on the green <>Code button on the Shrub Hub GitHub page then the Download Zip button on the popup.

#### Step C-04: Program the Shrub Hub

1. Copy the code.py file from the /Build_Files/Firmware_Files/Shrub Hub Firmware directory
2. Paste it into the CIRCUITPY drive, replacing the code.py file already there

### Optional: Changing the Shrub Hub Outputs

The outputs of each mode can be changed to better suit the needs of the user. The instructions for how to do this can be found in the Changing Outputs Guide in the Shrub Hub documentation folder. This requires opening and modifying the code, and should only be done by someone who is confident in their ability.

# Testing Guide

Once the Shrub Hub is programmed, connect assistive switches to each of the 3.5 mm inputs of the switch adapter, and connect the switch adapter to the Shrub Hub. Test that each switch produces the correct output, and that holding any switch for more than 4 seconds changes the mode. Mark each switch port with the correct switch input number if not already done.

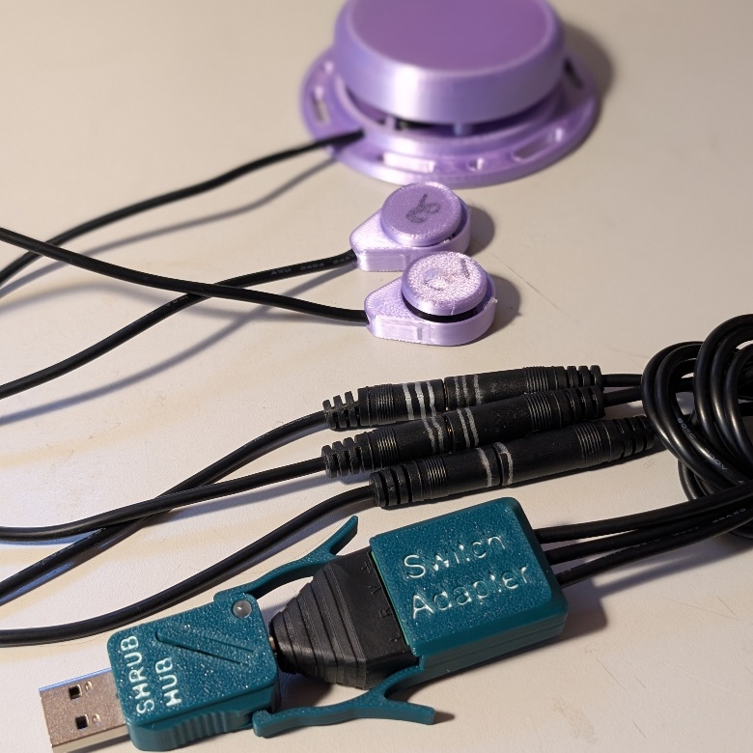
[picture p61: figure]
The Shrub Hub with the Switch Adapter connected with three assistive switches

Input | | Output
Activation | Input Switch | Mode 1 (Teal) | Mode 2 (Purple) | Mode 3 (Yellow) | Mode 4 (Green) | Mode 5 (Orange)
One Switch | Switch 1 | Enter | F1 | Left Click | F13 | Play/Pause
| Switch 2 | Space | F2 | Right Click | F14 | Volume Up
| Switch 3 | Tab | F3 | Middle Click | F15 | Volume Down
Two Switch | Switch 1+2 | Backspace | F4 | Left Click | F16 | Next Track
| Switch 2+3 | Escape | F5 | Right Click | F17 | Previous Track
| Switch 1+3 | Enter | F1 | Left Click | F13 | Play/Pause
Three Switch | Switch 1+2+3 | Enter | F1 | Left Click | F13 | Play/Pause

# Troubleshooting Guide

| Problem, Issue, or Concern | Cause | Remedy
1.1 | Nothing happens when switch is activated | Switch isn’t properly connected | Confirm that each switch is firmly connected to the intended input port.
1.2 | | Switch isn’t working | Confirm that the switch is working with a different device or switch tester.
1.3 | | A non-noticeable output is generated from a different operating mode than expected | Check the Mode Indicator to ensure that the Shrub Hub is in the desired operating mode. If not, Change Operating Mode.
1.4 | | Loose or disconnected Switch Adapter | Confirm that the Switch Adapter is securely connected to the Shrub Hub.
2.1 | Unexpected output is generated when switch is activated | Different switch activated | Confirm each switch is connected to the intended input port
2.2 | | Different operating mode than expected | Check the Mode Indicator to ensure that the Shrub Hub is in the desired operating mode. If not, Change Operating Mode.
3.1 | Mode Indicator is blinking yellow | Host device does not support USB HID | Connect Shrub Hub to a device that supports USB HID
3.2 | | Shrub Hub connected to USB Power Adapter | Connect Shrub Hub to a device that supports USB HID
4.1 | Mode Indicator is blinking red | The Shrub Hub code is not compiling | Revert the code to the latest version found on the Shrub Hub GitHub.
5.1 | The Shrub Hub freezes and does not respond to button presses | Shorted cables in Switch Adapter | Open the Switch Adapter enclosure and ensure there is no short between two of the cables.

# Support and Resources

Getting Help

The device referred to in this guide is an open-source assistive technology and is supported by a combination of documentation and community support.

If you need help building this device, please start by reviewing the documentation, including the

Troubleshooting Guide. If you are still having trouble, you can reach out for support in several ways:

1. Email the Makers Making Change Team at info@makersmakingchange.com.
2. Reach out to Makers Making Change on social media.

When asking for help, it is helpful to include:

- The name of the device
- A brief description of the issue
- What you were trying to do when the problem occurred
- Photos or videos, if available

Project Page & Documentation

The project page contains the most up-to-date information about this device, including documentation, design files, and known issues.

- Project page: https://github.com/makersmakingchange/Shrub-Hub

Reporting Issues or Suggesting Improvements

If you want to report a problem with the Shrub Hub, or suggest an improvement, you can get in touch in the following ways:

- Leave an issue on the GitHub repository, found at
  - https://github.com/makersmakingchange/Shrub-Hub/issues
- Send us an email at info@makersmakingchange.com

Open Source & Licensing

The device referred to in this guide is open-source assistive technology. This means the design files and documentation are publicly available and may be used, modified, and shared under the terms of the project’s license.

Open-source devices are often built and adapted by volunteers. While care is taken to provide accurate documentation, performance cannot be guaranteed in every situation. Always use your judgment and consult a professional if you have questions about suitability or safety.

© 2026 by Neil Squire. This work is licensed under the CC BY SA 4.0 License: http://creativecommons.org/licenses/by-sa/4.0 Files available at https://github.com/makersmakingchange/Shrub-Hub Page 1 of 1

V1.0| January 2026 Shrub Hub maker Guide

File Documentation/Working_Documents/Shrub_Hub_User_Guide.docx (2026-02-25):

# Overview

This document contains the necessary information to use the Shrub Hub, a low cost, easy to build digital switch interface.

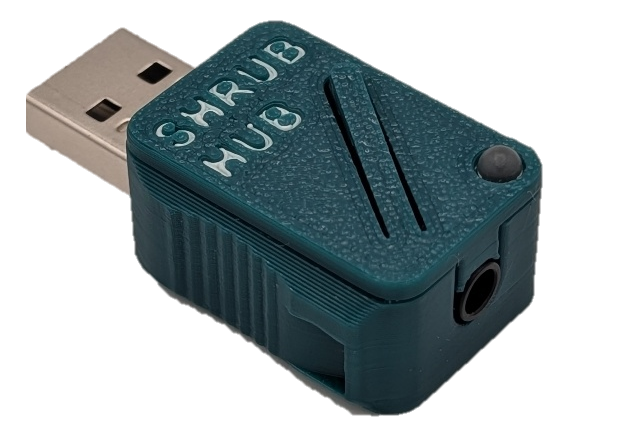
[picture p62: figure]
A close up of the Shrub Hub with the background removed

# Introduction

The Shrub Hub is a digital USB switch interface that allows a user to connect up to three 3.5 mm assistive switches to a digital device like a computer or mobile phone. It has five operating modes, and can send keystrokes, mouse clicks, and media control commands, with five outputs per mode. The Shrub Hub is powered from the device and does not require external power. The Shrub Hub uses standard USB Human Interface Device (HID) drivers and does not require the installation of any software.

It is designed to provide digital access to users using assistive switches, and to be low cost and very easy to build.

# Features

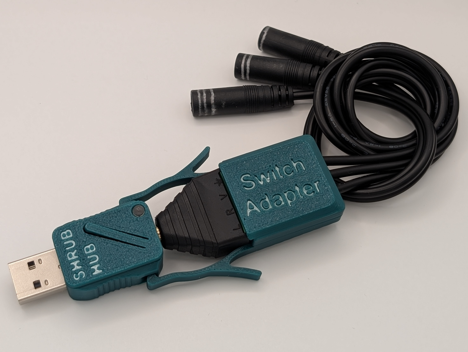
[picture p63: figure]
A labeled diagram of the Shrub Hub with the Switch Adapter connecter
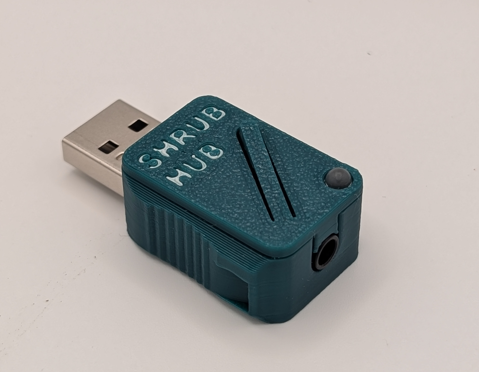
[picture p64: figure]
A diagram of the Shrub Hub with the features labeled

Mode Indicator

3-1 Switch Adapter

USB Connector

Switch Input Ports

Reset Button

Mode Indicator

USB Connector

Switch Input Jack

Reset Button

Switch Input Ports: The switch ports where 3.5 mm assistive switches can be connected.

USB Connector: The USB Connector is a USB-A plug that is inserted into a USB-A port on the Host Device.

Reset Button: The reset button of the microcontroller.

Mode Indicator: A multicolour LED that indicates the current operating mode.

3-1 Switch Adapter: An optional component that can be built and attached to the Shrub Hub. It can connect to up to three switches and allows the user to send inputs to the Shrub Hub using all three, instead of just one if the Switch Adapter is not used.

# Specifications

Item | Shrub Hub | Shrub Hub + Switch Adapter
Size (Length x Width x Height) [mm] | 40 x 20 x 10 | 100 x 40 x 10
Mass [g] | 8 | 48
Assistive Switch Inputs | 1 | 3
Configurable Outputs per Mode | 1 | 5

# Compatibility

Assistive Switches: The Shrub Hub is compatible with up to 3 assistive switches that have a 3.5 mm plug.

Host Device: The Shrub Hub is compatible with any digital host device that accepts USB HID inputs and has a USB-A port, such as a computer or mobile device. If the connected device does not have a USB-A port, an adapter will be needed. If used with an iOS device, it will need a separate power source as described in the iOS use section.

# Usage

The Shrub Hub is a digital switch interface that generates outputs to a host device (e.g., computer, smartphone) when the attached assistive switches are activated. The initial setup involves attaching 1-3 assistive switches to the Shrub Hub, or via the Switch Adapter, then connecting the Shrub Hub to the host device. During use, the Shrub Hub will generate USB HID outputs such as keystrokes, mouse clicks, or media control inputs depending on the operating mode when the connected assistive switches are activated. The current operating mode is indicated by the colour of the indicator light. The operating mode can be changed by performing a long press (holding for longer than four seconds) on a connected assistive switch.

## Initial Setup

The Shrub Hub can be setup in two configurations: a Single Switch Configuration for use with a single assistive switch, or 1-3 Switch Configuration for use with 1, 2, or 3 assistive switches. The configurations differ by whether the 1-3 Switch Adapter is required.

| Configuration
| Single Switch Configuration | 1-3 Switch Configuration
Hardware | Shrub Hub | Shrub Hub + Switch Adapter
Assistive Switches | 1 | 1, 2, or 3
Outputs Per Mode | 1 | 5

### Single Switch Configuration

If a user is only going to use a single assistive switch, the switch can be plugged directly into the Shrub Hub. When using a single switch, the Shrub Hub reads the switch as Switch 1+3 or Switch 1+2+3 (depending on the type of cable) on Table 1 found below, which functions the same as Switch 1.

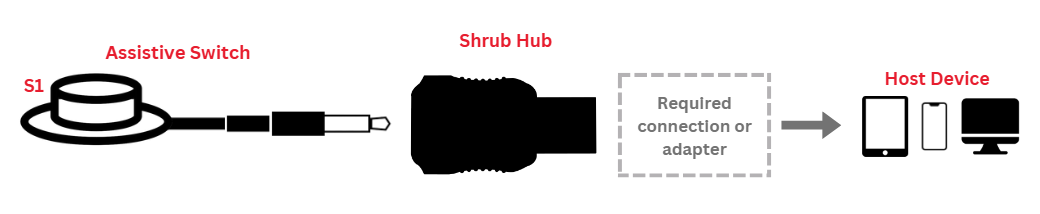
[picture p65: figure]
A connection diagram of the Shrub Hub connecting to a switch and a host device

### 1-3 Switches

When setting up the Shrub Hub with more than one switch, the first step is to connect the Switch Adapter to the Shrub Hub.

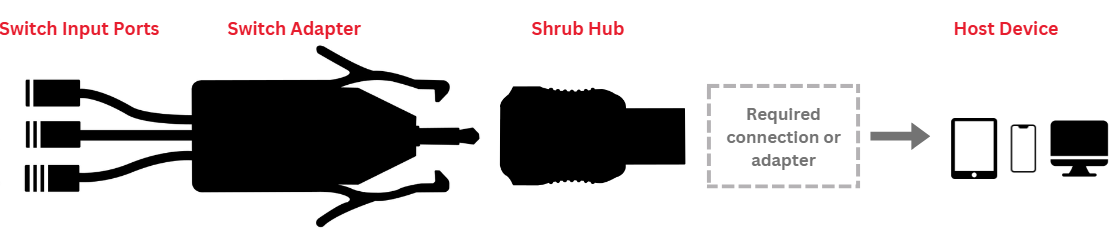
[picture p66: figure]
A connection diagram of the Shrub Hub connecting to the Switch Adapter and a host device

After plugging in the Switch Adapter, plug Switch 1 into Switch Input Port 1, Switch 2 into Switch Input Port 2, and Switch 3 into Switch Input Port 3. The cables may have been marked by the maker of the device, but if not, they should be marked on the first use to make future setups easier. The easiest way to mark them will be to plug in the device and press each button. Refer to Table 1 on the last page of the guide for which button should output which keystroke. Using the switch outputs, you can determine which switch is which and label the splitter cables as such.

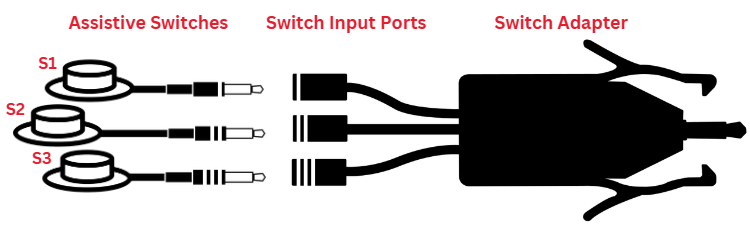
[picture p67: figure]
A diagram showing connecting switches to the Switch Adapter

## Regular Use

### Connecting to Host Device

After plugging in the switch or switches to the Shrub Hub, plug the Hub into a USB-A port on the host device.

- For host devices with a USB-A port (e.g., computer), the Shrub Hub can be connected directly or connected via a USB-A extension cable.
- For host devices without a USB port other than USB-A, use a suitable adapter.
- For iOS devices, a powered USB Hub or powered USB splitter is required to connect the Shrub Hub to the device.

Once connected and powered, a light on the Shrub Hub will turn on and indicate the Operating Mode, at which point the Hub is ready to use.

### Generating Output

Once the Hub is ready to use, activating one or more of the connected switches will generate the corresponding output based on the current Operating Mode. The output will be produced when the switch is released.

#### Single Switch Activation

When pressing a single switch, once the switch is released, the Shrub Hub will send one of the outputs in the one switch section in the below table, depending on the button pressed and the mode of the device.

#### Multiple Switch Activation (Chording)

If two or more switches are activated simultaneously, a different output will be produced.

While the Shrub Hub has three switch inputs when using the Switch Adapter, it can send up to five different outputs using chording, which is pressing multiple switches at the same time. A chorded input is activated on the Shrub Hub when two switches are released within 0.5 seconds of each other.

The Shrub Hub currently only has chorded outputs on switches 1+2 and switches 2+3; switches 1+3 and switches 1+2+3 perform the same output as switch 1 as plugging a single switch into the Shrub Hub directly instead of using the Switch Adapter will send the same signal as using the Switch Adapter with those chorded inputs.

See the below table for the full list of outputs.

## Operating Modes and Outputs

The Shrub Hub has different outputs depending on the operating mode. The different operating modes are as follows:
Operating Mode 1 – This mode has the keystrokes Enter, Space, Tab, Backspace, and Escape. These keystrokes can be used to navigate a web browser, or for switch scanning on a mobile device.

Operating Mode 2 – This mode has the first five function keys, F1-F5. These keystrokes can be used for switch scanning on a mobile device

Operating Mode 3 – This mode has left, right, and middle mouse clicks. This mode can be used in tandem with a USB joystick to move the mouse, then use the Shrub Hub to click on items.

Operating Mode 4 – This mode has the first five unused function keys. They are unused in most programs, and can be used with programs such as AutoHotkey to trigger preprogrammed actions or scripted programs.

Operating Mode 5 – This mode has the media control commands Play/Pause, Volume Up, Volume Down, Next Track, and Previous Track. This allows the Shrub Hub to be used to control the media playing on the connected device.

Table 1: Default outputs for each Operating Mode in multiple switch mode

Input | | Output
Activation | Input Switch | Mode 1 (Teal) | Mode 2 (Purple) | Mode 3 (Yellow) | Mode 4 (Green) | Mode 5 (Orange)
One Switch | Switch 1 | Enter | F1 | Left Click | F13 | Play/Pause
| Switch 2 | Space | F2 | Right Click | F14 | Volume Up
| Switch 3 | Tab | F3 | Middle Click | F15 | Volume Down
Two Switch | Switch 1+2 | Backspace | F4 | Left Click | F16 | Next Track
| Switch 2+3 | Escape | F5 | Right Click | F17 | Previous Track
| Switch 1+3 | Enter | F1 | Left Click | F13 | Play/Pause
Three Switch | Switch 1+2+3 | Enter | F1 | Left Click | F13 | Play/Pause

Table 2: Default outputs for each Operating Mode in single switch mode

Input | | Output
Activation | Input Switch | Mode 1 (Teal) | Mode 2 (Purple) | Mode 3 (Yellow) | Mode 4 (Green) | Mode 5 (Orange)
One Switch | Switch 1 | Enter | F1 | Left Click | F13 | Play/Pause

### Changing Operating Mode

The current Operating Mode is indicated by the colour of the Mode Indicator on the Shrub Hub. The Operating Mode can be changed so that the Shrub Hub generates a different set of outputs.

To change Operating Modes, hold any switch for more than four (4) seconds. The Mode Indicator will turn off when the switch has been pressed and turn back on with the same colour once the mode change time has been exceeded (i.e., when the switch has been held for at least four seconds). Once the switch has been released, the mode colour light will change to the colour of the next mode and the Shrub Hub will not send an output. The mode cannot change more than once per switch press and will not change until the switch is released.

### Changing Outputs

The outputs of each mode can be changed to better suit the needs of the user. The instructions for how to do this can be found in the Changing Outputs Guide in the Shrub Hub documentation folder. This requires opening and modifying the code, and should only be done by someone who is confident in their ability.

## Storage

Disconnect the assistive switches by gripping the plug and jack and gently pulling apart.

When not in use, the Shrub Hub should be stored in a cool place out of direct sunlight.

# Care

The Shrub Hub enclosure is made of 3D printed plastic. Exposure to high heat may cause warping and/or negatively affect function. Extended exposure to sunlight will also weaken the plastic on the device.

The Shrub Hub contains electronics and is not waterproof. If the device becomes wet, make sure it is disconnected and do not use it until it has completely dried. It may help to open the enclosures to speed up drying and ensure it has completely dried.

## Cleaning

The Shrub Hub can be wiped with a damp cloth while unplugged from the device.

## End of Life / Disposal

PLA filament may be industrially compostable in your area. Check with your waste management company if PLA can be composted or must be thrown in the garbage.

Disassemble the Shrub Hub and separate out the recyclable and compostable components, and those that must be thrown out. Electronics and batteries should be disposed of following your local waste management guidelines.

# Changing the Outputs

For some users, the provided switch outputs may not meet their needs. It is possible to edit the outputs of the Shrub Hub, but this involves editing the code stored on the device. This is not an easy process, and should only be done if you feel confident and while carefully following the instructions.

Detailed instructions on how to change settings on the Shrub Hub can be found in the Shrub Hub Changing Outputs Guide, found here (https://github.com/makersmakingchange/Shrub-Hub/blob/main/Documentation/Shrub_Hub_Changing_Outputs_Guide.pdf), or at the following QR code.

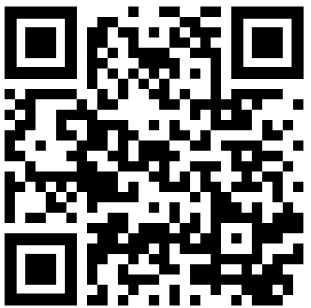
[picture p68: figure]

Figure 1: QR Code Link to the Changing Outputs Guide

# Troubleshooting

This section helps you identify and fix common issues when using the Shrub Hub. If the problem persists after trying the steps below, see the Support and Resources section.

## Quick Checks

- Make sure the Shrub Hub is securely connected to a USB port on host device.
- Verify that the cable of each assistive switch is firmly attached to the corresponding input port.
- Verify that the Mode Indicator is lit and showing the color of the intended operating mode.

## Common Problems and Solutions

| Problem, Issue, or Concern | Cause | Remedy
1.1 | Nothing happens when switch is activated | Switch isn’t properly connected | Confirm that each switch is firmly connected to the intended input port.
1.2 | | Switch isn’t working | Confirm that the switch is working with a different device or switch tester.
1.3 | | A non-noticeable output is generated from a different operating mode than expected | Check the Mode Indicator to ensure that the Shrub Hub is in the desired operating mode. If not, Change Operating Mode.
1.4 | | Loose or disconnected Switch Adapter | Confirm that the Switch Adapter is securely connected to the Shrub Hub.
2.1 | Unexpected output is generated when switch is activated | Different switch activated | Confirm each switch is connected to the intended input port
2.2 | | Different operating mode than expected | Check the Mode Indicator to ensure that the Shrub Hub is in the desired operating mode. If not, Change Operating Mode.
3.1 | Mode Indicator is blinking yellow | Host device does not support USB HID | Connect Shrub Hub to a device that supports USB HID
3.2 | | Shrub Hub connected to USB Power Adapter | Connect Shrub Hub to a device that supports USB HID
4.1 | Mode Indicator is blinking red | The Shrub Hub code is not compiling | Revert the code to the latest version found on the Shrub Hub GitHub.
5.1 | The Shrub Hub freezes and does not respond to button presses | Shorted cables in Switch Adapter | Open the Switch Adapter enclosure and ensure there is no short between two of the cables.

# Support and Resources

## Getting Help

The device referred to in this guide is an open-source assistive technology and is supported by a combination of documentation and community support.

If you need help using this device, please start by reviewing the documentation, including the Troubleshooting section. If you are still having trouble, you can reach out for support in several ways:

1. Email the Makers Making Change Team at info@makersmakingchange.com.
2. Reach out to Makers Making Change on social media.

When asking for help, it is helpful to include:

- The name of the device
- A brief description of the issue
- What you were trying to do when the problem occurred
- Photos or videos, if available

## Project Page & Documentation

The project page contains the most up-to-date information about this device, including documentation, design files, and known issues.

- Project page: https://github.com/makersmakingchange/Shrub-Hub
- User Guide: https://github.com/makersmakingchange/Shrub-Hub/blob/main/Documentation/Shrub_Hub_User_Guide.pdf

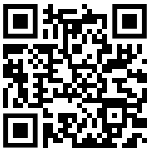
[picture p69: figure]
A qr code on a white background that links to the project files

Figure 2: QR code link to project files

## Reporting Issues or Suggesting Improvements

If you want to report a problem with the Shrub Hub, or suggest an improvement, you can get in touch in the following ways:

- Leave an issue on the GitHub repository, found at
  - https://github.com/makersmakingchange/Shrub-Hub/issues
- Send us an email at info@makersmakingchange.com

## Open Source & Licensing

The device referred to in this guide is open-source assistive technology. This means the design files and documentation are publicly available and may be used, modified, and shared under the terms of the project’s license.

Open-source devices are often built and adapted by volunteers. While care is taken to provide accurate documentation, performance cannot be guaranteed in every situation. Always use your judgment and consult a professional if you have questions about suitability or safety.

© 2026 by Neil Squire. This work is licensed under the CC BY SA 4.0 License: http://creativecommons.org/licenses/by-sa/4.0 Files available at https://github.com/makersmakingchange/Shrub-Hub Page 2 of 3

V1.0 | January 2026 Shrub Hub user Guide

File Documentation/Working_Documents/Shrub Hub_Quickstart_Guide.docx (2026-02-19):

# Features

A labeled diagram of the Shrub Hub with the Switch Adapter connecter
A diagram of the Shrub Hub with the features labeled

Mode Indicator

3-1 Switch Adapter

USB Connector

Switch Input Ports

Reset Button

Mode Indicator

USB Connector

Switch Input Jack

Reset Button

Operating Mode in Single Switch Mode

Input | | Output
Activation | Input Switch | Mode 1 (Teal) | Mode 2 (Purple) | Mode 3 (Yellow) | Mode 4 (Green) | Mode 5 (Orange)
One Switch | Switch 1 | Enter | F1 | Left Click | F13 | Play/Pause

Operating Mode in Multiple Switch Mode

Input | | Output
Activation | Input Switch | Mode 1 (Teal) | Mode 2 (Purple) | Mode 3 (Yellow) | Mode 4 (Green) | Mode 5 (Orange)
One Switch | Switch 1 | Enter | F1 | Left Click | F13 | Play/Pause
| Switch 2 | Space | F2 | Right Click | F14 | Volume Up
| Switch 3 | Tab | F3 | Middle Click | F15 | Volume Down
Two Switch | Switch 1+2 | Backspace | F4 | Left Click | F16 | Next Track
| Switch 2+3 | Escape | F5 | Right Click | F17 | Previous Track
| Switch 1+3 | Enter | F1 | Left Click | F13 | Play/Pause
Three Switch | Switch 1+2+3 | Enter | F1 | Left Click | F13 | Play/Pause

The operating mode can be changed by performing a long press (holding for longer than four seconds) on any connected switch.

## Setup

### Single Switch Configuration

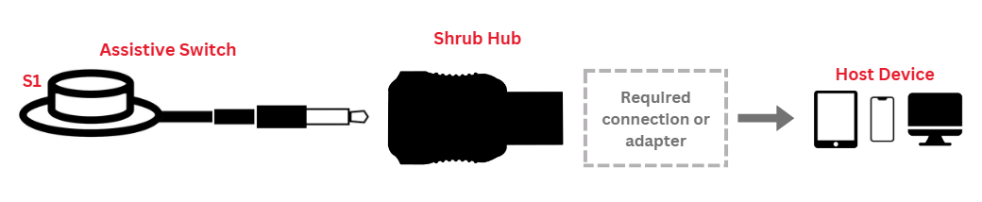
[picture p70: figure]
A connection diagram of the Shrub Hub in single switch mode

### 1-3 Switches

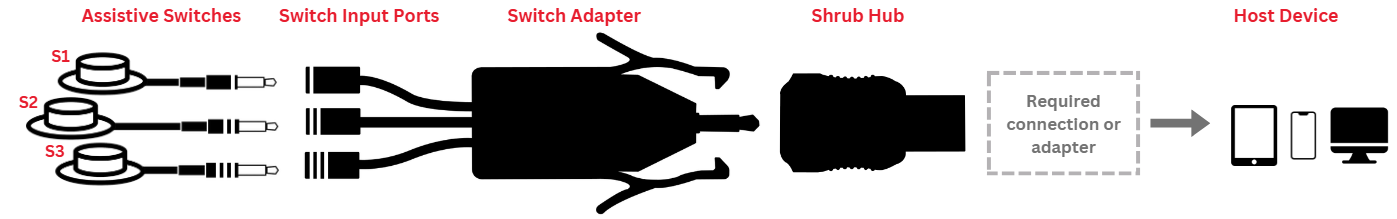
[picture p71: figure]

If the connected device does not have a USB-A port, an adapter will be needed. If used with an iOS device, it will need a separate power source as described in the iOS use section.

# Further Information

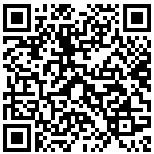
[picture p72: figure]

If you are looking for information on troubleshooting, support, or any other questions, refer to the User Guide. | User Guide (https://github.com/makersmakingchange/Shrub-Hub/blob/main/Documentation/Shrub_Hub_User_Guide.pdf)

© 2026 by Neil Squire. This work is licensed under the CC BY SA 4.0 License: http://creativecommons.org/licenses/by-sa/4.0 Files available at https://github.com/makersmakingchange/Shrub-Hub Page 2 of 3

V1.0 | January 2026 Shrub Hub Quickstart Guide

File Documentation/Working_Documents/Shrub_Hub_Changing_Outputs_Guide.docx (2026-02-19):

# Introduction

The Shrub Hub comes with a total of twenty-five different outputs, split into five modes of five outputs each. These outputs were chosen based on existing digital interfaces and input from clinicians, but they may not be the ideal outputs for your use case. If that is the case, you can change the outputs that the Shrub Hub has to better suit your needs.

The different outputs of the various modes can be modified by a skilled Maker or Secondary User.

# Feedback

If you do change the outputs for your Shrub Hub, please get in touch with us to tell us what you changed them to so we can better understand the needs of the Shrub Hub users and change the default outputs to better represent the needs of the users.

You can get in touch with us in any of the following ways

- Email us at info@makersmakingchange.com
- File a GitHub Issue at the following link: GitHub Issues (https://github.com/makersmakingchange/Shrub-Hub/issues)

# Changing the Code

The Shrub Hub has several settings that can be changed to adjust its operation.

Modifying these settings involves modifying text in the code file. This should be done with caution, as it is possible to break the code by making changes to it. Always make a backup of the file before making any changes.

## Accessing Code to Make Changes

To change the settings on the Shrub Hub, you first must access the code. The code can be found by opening the file explorer on your computer when the Shrub Hub is plugged in, and there should be a drive called CIRCUITPY that appears similar to plugging in a USB flash drive. Clicking on this drive should show a folder called lib, and a file called code.py. The code is stored in the code.py file, which can be opened using notepad or a code editing program. The program Mu was used to develop the code, and it can be downloaded at this link: Mu Code Editor (https://codewith.mu/).

After opening code.py in your program of choice, the settings for the Shrub Hub are found in the settings section of the code, which starts here, labeled with SETTINGS and DO NOT CHANGE ANYTHING ABOVE THIS LINE.

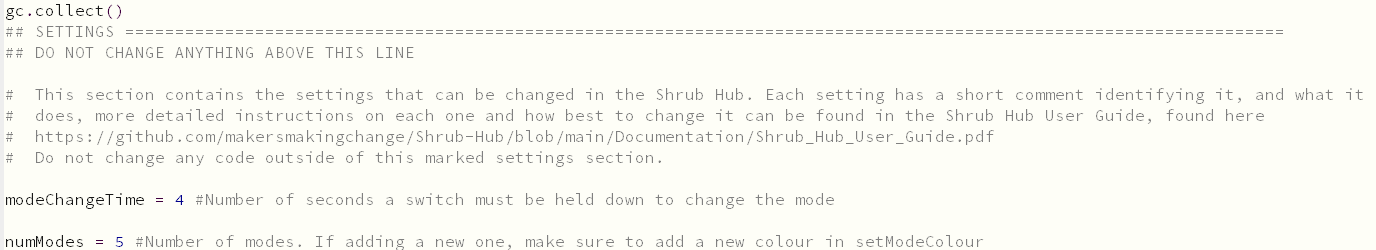
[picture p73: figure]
The section of the code that starts the settings section

And ends here, labeled with END OF SETTINGS and DO NOT CHANGE ANYTHING BELOW THIS LINE.

In this section, there are four user changeable settings. These settings are modeChangeTime, numModes, colourMatrix, and keystrokeMatrix.

## Changing Mode Change Time

modeChangeTime is the simplest setting to change. This setting controls the number of seconds that a switch needs to be held down before it changes the mode. The default for this is four seconds and changing it will change the amount of time the switch needs to be held down.

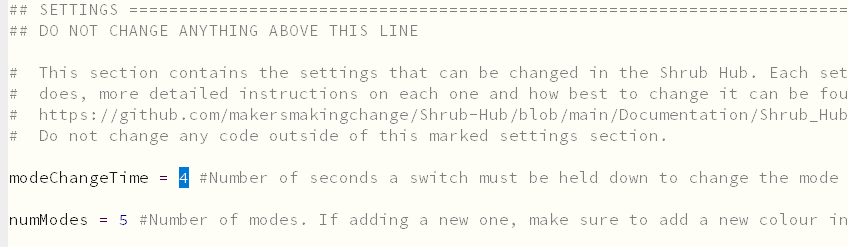
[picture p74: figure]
The highlighted number that controls the number of seconds it takes to change the mode

## Changing the Number of Modes

numModes is the number of modes that the Shrub Hub has. This is currently set to five. To change this, you also need to change the number of rows in both of the next two settings. If it is less than the number of rows, you will never be able to access some of the modes, and if it is greater than the number of rows the Shrub Hub will crash and stop working when you try and change the mode. For example, if this is set to three without changing anything else, it will be impossible to access modes four and five. If it is set to six, the Shrub Hub will crash when trying to change out of mode five.

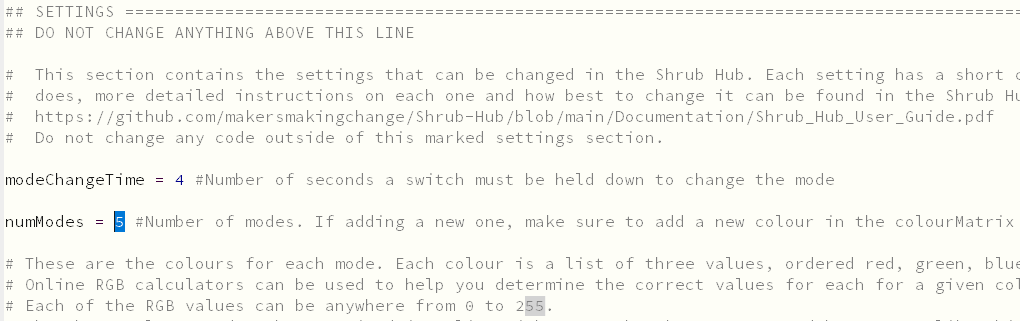
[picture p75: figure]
The highlighted number that controls the number of modes

## Changing the Mode Colour

colourMatrix is where the Shrub Hub stores information on what colour the NeoPixel should be in each mode. The colour matrix is organized in a list and can be read as colourMatrix = [mode1colour, mode2colour, mode3colour, mode4colour, mode5colour] with new lines added for legibility. Each individual mode colour is made up of three numbers that contain amount of red, green, and blue (RGB) in each colour, and is formatted in square brackets as [Red, Green, Blue]. These numbers can be anywhere from 0 to 255, and online RGB calculators can be used to determine the correct RGB numbers for any given colour.

### Example Colour Change

As an example, if you wanted to change the colour of mode four to be magenta instead of green, these are the steps that you would follow to do so.

The first step is to find the section that you want to change. We want to change the colour of mode four, so we look at the fourth row, helpfully labelled with the comment Mode 4 = Green. This row contains the list [0, 60, 0], which is the RGB colour code of the mode. The R stands for red, and the first entry is zero, which means that there is no red. The G stands for green, and the second entry is 60, which means the green is set to 60 out of a maximum of 255. Finally, the B stands for blue, and the third entry is set to zero which means that there is no blue. This leaves us with only a green light set to roughly one third power as to not be too bright.

The next step is to determine the colour code for the new colour we want. Since we are going for a magenta colour, we search online to find the colour code. The RGB of magenta is found to be 255, 0, 255, which is equal parts red and blue. Since this will be quite bright, we will turn it down to 128, 0, 128. The balance between the colours is not changing, we are just turning down the brightness.

Finally, we go into the colourMatrix to replace the old RGB code for mode 4 with the new code. We replace the [0, 60, 0] with [128, 0, 128], and update the comment to show the new mode colour. The final results should look like this.

## Changing Shrub Hub Outputs

If the user wants different outputs than the defaults, it is possible to change them. The outputs for the different mode are stored in the keystrokeMatrix variable. The keystroke matrix is organized in a list and can be read as keystrokeMatrix = [mode1keystrokes, mode2keystrokes, mode3keystrokes, mode4keystrokes, mode5keystrokes].

Each mode keystrokes is also made up of a list that is structured like [switch1keystroke, switch2keystroke, switch3keystroke, switch4keystroke, switch5keystroke]. This leads to a matrix that looks like the following,

keystrokeMatrix =

[[switch1keystroke, switch2keystroke, switch3keystroke, switch4keystroke, switch5keystroke],

[switch1keystroke, switch2keystroke, switch3keystroke, switch4keystroke, switch5keystroke],

[switch1keystroke, switch2keystroke, switch3keystroke, switch4keystroke, switch5keystroke],

[switch1keystroke, switch2keystroke, switch3keystroke, switch4keystroke, switch5keystroke],

[switch1keystroke, switch2keystroke, switch3keystroke, switch4keystroke, switch5keystroke]]

Finally, each individual keystroke is made of a set of two lists that look like this [identifier, [keystroke1, keystroke2, etc.]]. The identifier is either 1, 2, or 3, and it tells the program if it is a keystroke(1), a mouse click(2), or a media control command(3). The list of keystrokes will commonly be a single keystroke, but there is support for multiple keystrokes if you want to have the device send a CTRL + C or CTRL + SHIFT + T for example. Example valid entries can look like [1, [Keycode.TAB]], [1, [Keycode.GUI, Keycode.H]], [1, [Keycode.CONTROL, Keycode.SHIFT, Keycode.T]], [2, [Mouse.LEFT_BUTTON]], [3, [ConsumerControlCode.PLAY_PAUSE]]

The full list of valid keycodes can be found at the following link: Keycode List (https://docs.circuitpython.org/projects/hid/en/latest/api.html).

### Example Keycode Change

#### Changing a Keystroke

As an example of changing a keystroke, we are going to look at changing Output 3 on Mode 2 from F3 to a 3.

The first step is to find the output that you want to change. Since we are looking to change something in Mode 2, find the second row of the keystrokeMatrix. In the second row, find the third entry. This may sound complicated, but it is made easier by the fact that the entries are separated by commas, and often contain the name of the keystroke in capital letters. In this case, we are looking for the entry [1, [Keycode.F3]]. Since we are just looking to change a keystroke, we can leave the 1 alone and focus on the Keycode.F3.

Now that we have found the output that we want to change, the next step is to find what we want to change it to. Keycodes for every output can be found at the following link: Keycode List (https://docs.circuitpython.org/projects/hid/en/latest/api.html). Since we want to change it to a 3, we go to the keycode section of the linked site and find that the code for a 3 is Keycode.THREE.

Now that we have our new keycode and we know where it goes, we simply replace the Keycode.F3 with Keycode.THREE so that entry looks like [1, [Keycode.THREE]]. Save the code and now pressing the switch connected to Switch Input Port 3 while in mode 2 should send the character 3 instead of F3.

#### Changing an Output Type

A more complicated change would be to change a keystroke to a mouse click or a media control command. For this, we are going to look at changing Output 3 on Mode 2 from F3 to the media control command mute.

Following the steps from the previous section, find the section that you want to change. In our case, it is the entry [1, [Keycode.F3]]. Since we are changing it from keystrokes to media controls, we have to change more things than the previous section. The first thing to change is the mode indicator, which is the 1 at the beginning of the entry. The 1 tells the program that it is a keycode, we want to change that to a 3 since we are changing to a media command. If we were changing it to a mouse command we would use a 2.

The next step is to change the code prefix. On the current entry it is Keycode, but since we are changing it to a media control command we want to change it to ConsumerControlCode. If we were changing it to a mouse command we would change it to Mouse.

Finally, we need to find what command we want to change it to. The different media control commands can be found at the following link: Command List (https://docs.circuitpython.org/projects/hid/en/latest/api.html). Scrolling down to the ConsumerControlCode section on the page, we find that the code for mute is MUTE.

Now that we know the three things that we need to change, we change the [1, [Keycode.F3]] to [3, [ConsumerControlCode.MUTE]]. Save the code, and now pressing the switch connected to Switch Input Port 3 while in mode 2 should mute or unmute the audio of the device instead of sending the character F3.

## Output Link

The keycodes, mouse clicks, and consumer control codes can be found here or at the following QR code: https://docs.circuitpython.org/projects/hid/en/latest/api.html

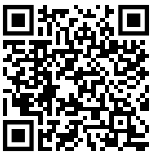
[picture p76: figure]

© 2026 by Neil Squire. This work is licensed under the CC BY SA 4.0 License: http://creativecommons.org/licenses/by-sa/4.0 Files available at https://github.com/makersmakingchange/Shrub-Hub Page 1 of 6

V1.0 | January 2026 Shrub Hub Changing Outputs Guide

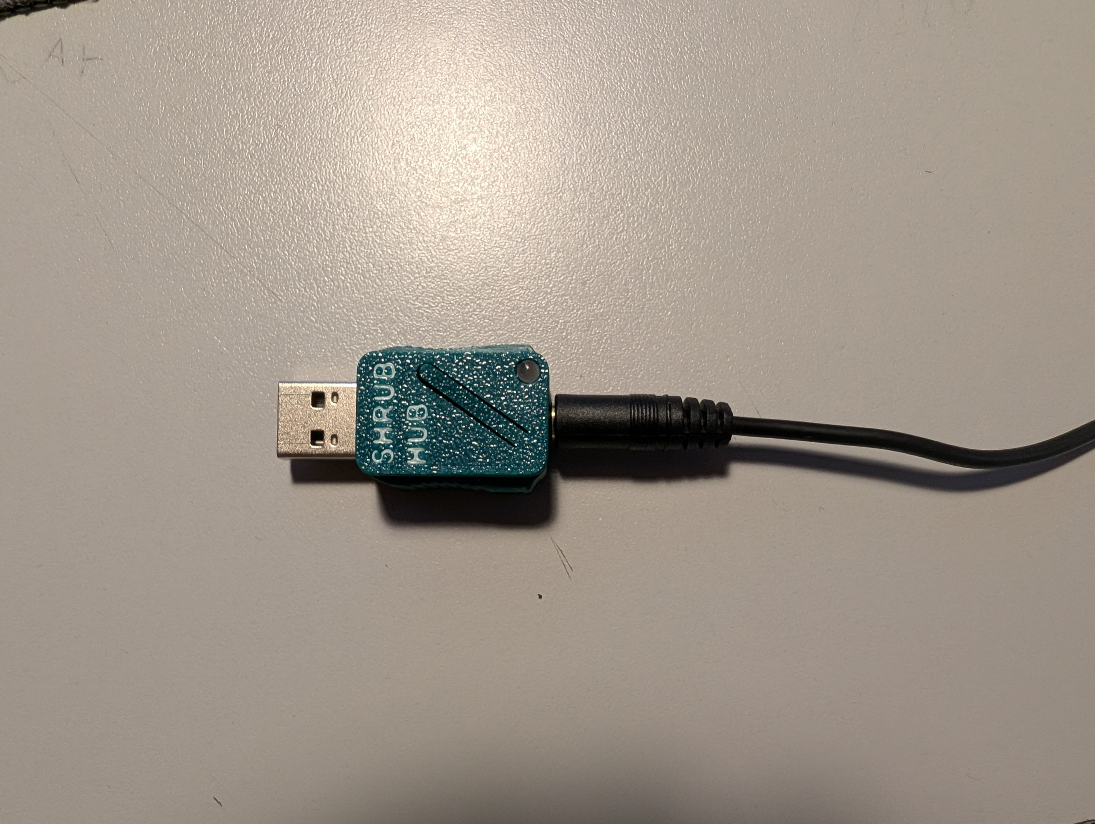
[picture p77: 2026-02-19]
Documentation/Working_Documents/Assets/Single switch shrub hub assembled.jpg

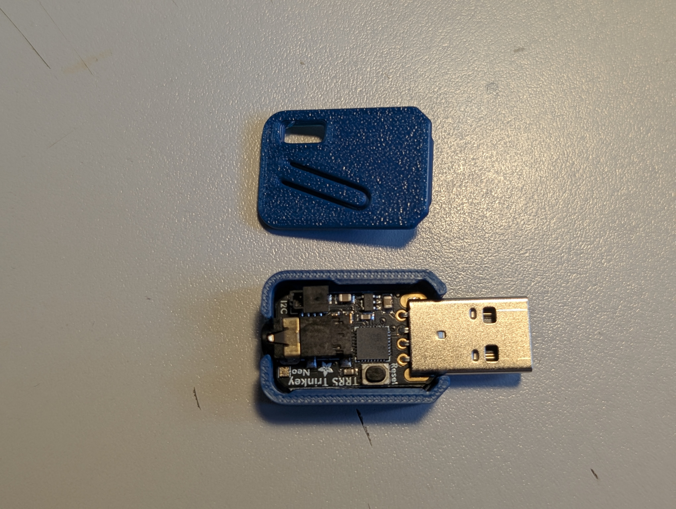
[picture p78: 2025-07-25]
Documentation/Working_Documents/Assets/Mid_Assembly.jpg

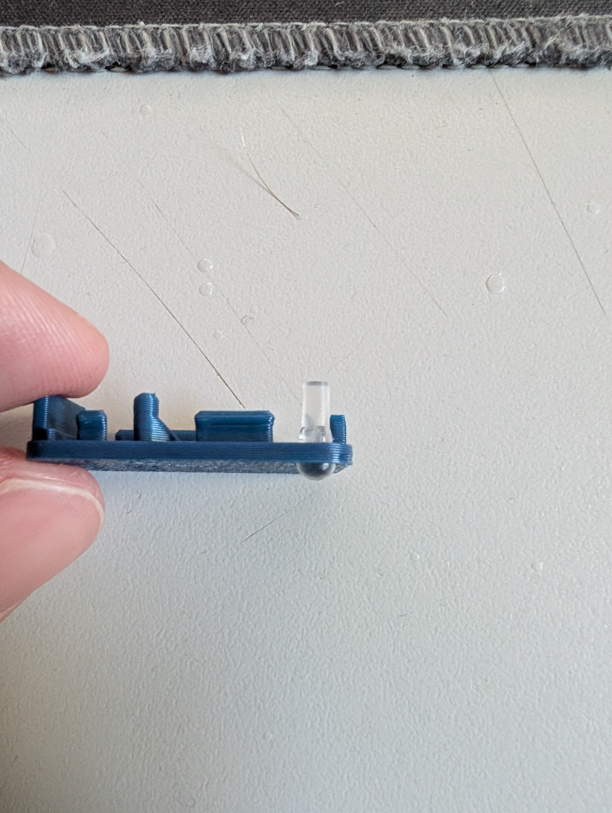
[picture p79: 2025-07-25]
Documentation/Working_Documents/Assets/Assembled Light Pipe.jpg

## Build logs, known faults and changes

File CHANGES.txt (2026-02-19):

Version 1.0 | 2026-01-12
 - Changed the code to allow the device to work without the Switch Adapter using a single switch

Version 0.2 | 2025-11-04
 - Updated enclosure based on user feedback
	- Made it easier to find the reset button
	- Made it easier to grip the enclosure to unplug it
	- Added a connector between the Shrub Hub and Switch Adaptor 
 - Removed 1-5 mode
 - Added mouse clicks and media control
 - Made mode persistent between reboots

Version 0.1 | 2025-07-16
 - Initial Prototype
 - Modified software to include different operational modes
 - Created alternate, cheaper switch splitter

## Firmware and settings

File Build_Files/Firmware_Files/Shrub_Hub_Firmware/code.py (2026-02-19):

#  File: code.py
#  Firmware: Shrub Hub
#  Developed by: Neil Squire Society / Makers Making Change Program
#  Version: v1.0.0 (15 Dec 2025)
#  License: GPL v3.0 or later
#
#  This is the firmware for the Shrub Hub, a low cost, easy to build three switch digital interface
#  that lets a user send keystrokes, mouse clicks, and media control commands to a connected device.
#  The device allows a user to change modes by holding down any switch for a set period of time, and supports switch chording.
#
#  The firmware has a editable settings section that can be used to change settings such as the number of modes, the LED
#  indicator colours for each mode, the amount of time a switch must be held down to switch mode, and the keystrokes used in
#  each mode. This section is clearly marked in the code, and changing anything outside of this section is not recommended.
#  Detailed instructions on how to change the settings can be found in the user guide.
#
#  Copyright (C) 2025 - 2026 Neil Squire Society
#  This program is free software: you can redistribute it and/or modify it under the terms of
#  the GNU General Public License as published by the Free Software Foundation,
#  either version 3 of the License, or (at your option) any later version.
#  This program is distributed in the hope that it will be useful, but WITHOUT ANY WARRANTY;
#  without even the implied warranty of MERCHANTABILITY or FITNESS FOR A PARTICULAR PURPOSE.
#  See the GNU General Public License for more details.
#  You should have received a copy of the GNU General Public License along with this program.
#  If not, see <http://www.gnu.org/licenses/>

# The GitHub repository for this device can be found here, along with the documentation and all project files
# https://github.com/makersmakingchange/Shrub-Hub

# import libraries
import time
import board
import gc
import digitalio
import neopixel
import usb_hid
import microcontroller
from adafruit_hid.keyboard import Keyboard
from adafruit_hid.keycode import Keycode
from adafruit_hid.consumer_control import ConsumerControl # For media control
from adafruit_hid.consumer_control_code import ConsumerControlCode
from adafruit_hid.mouse import Mouse

# --- HID Keyboard, Mouse, and Media Control and Neopixel Setup ---
keyboard = Keyboard(usb_hid.devices)
mouse = Mouse(usb_hid.devices)
cc = ConsumerControl(usb_hid.devices)
pixel = neopixel.NeoPixel(board.NEOPIXEL, 1)

gc.collect()
## SETTINGS ====================================================================================================================
## DO NOT CHANGE ANYTHING ABOVE THIS LINE

#  This section contains the settings that can be changed in the Shrub Hub. Each setting has a short comment identifying it, and what it
#  does, more detailed instructions on each one and how best to change it can be found in the Shrub Hub User Guide, found here
#  https://github.com/makersmakingchange/Shrub-Hub/blob/main/Documentation/Shrub_Hub_User_Guide.pdf
#  Do not change any code outside of this marked settings section.

modeChangeTime = 4 #Number of seconds a switch must be held down to change the mode

numModes = 5 #Number of modes. If adding a new one, make sure to add a new colour in the colourMatrix

# These are the colours for each mode. Each colour is a list of three values, ordered red, green, blue.
# Online RGB calculators can be used to help you determine the correct values for each for a given colour.
# Each of the RGB values can be anywhere from 0 to 255.
# The three values need to be organized in a list with square brackets, seperated by commas, like this: [R, G, B]

colourMatrix = [[0, 128, 128], # Mode 1 = Teal
               [50, 0, 128],  # Mode 2 = Purple
               [50, 60, 0],   # Mode 3 = Yellow
               [0, 60, 0],    # Mode 4 = Green
               [120, 60, 0]]  # Mode 5 = Orange

# Keystrokes used for the different switch and mode combinations
# https://docs.circuitpython.org/projects/hid/en/latest/api.html
# Reference for changing these keycodes
# Keystrokes are stored in a two dimensional matrix of lists. The rows are the modes, and the columns are the buttons
# Each keystroke consists of an identifier, and a list of keycodes. If using a single keystroke, it still must be in a list
# The identifier 1 is used for keystrokes, 2 for mouse clicks, and 3 for media control
# Example valid entries: [1, [Keycode.TAB]], [1, [Keycode.GUI, Keycode.H]], [1, [Keycode.CONTROL, Keycode.SHIFT, Keycode.T]], [2, [Mouse.LEFT_BUTTON]]

# Detailed instructions on how to change the keystroke matrix can be found in the user guide, linked at the bottom of this comment.
# This is the hardest setting to change, make sure to read the user guide before making any changes to reduce the chances of making a mistake
# https://github.com/makersmakingchange/Shrub-Hub/blob/main/Documentation/Shrub_Hub_User_Guide.pdf

keystrokeMatrix = [[[1, [Keycode.ENTER]], [1, [Keycode.SPACE]], [1, [Keycode.TAB]], [1, [Keycode.BACKSPACE]], [1, [Keycode.ESCAPE]]], #teal, Mode 1
                   [[1, [Keycode.F1]], [1, [Keycode.F2]], [1, [Keycode.F3]], [1, [Keycode.F4]], [1, [Keycode.F5]]], #purple, Mode 2
                   [[2, [Mouse.LEFT_BUTTON]], [2, [Mouse.RIGHT_BUTTON]], [2, [Mouse.MIDDLE_BUTTON]], [2, [Mouse.LEFT_BUTTON]], [2, [Mouse.RIGHT_BUTTON]]], #yellow, Mode 3
                   [[1, [Keycode.F13]], [1, [Keycode.F14]], [1, [Keycode.F15]], [1, [Keycode.F16]], [1, [Keycode.F17]]], #green, Mode 4
                   [[3, [ConsumerControlCode.PLAY_PAUSE]], [3, [ConsumerControlCode.VOLUME_INCREMENT]], [3, [ConsumerControlCode.VOLUME_DECREMENT]], [3, [ConsumerControlCode.SCAN_NEXT_TRACK]], [3, [ConsumerControlCode.SCAN_PREVIOUS_TRACK]]]]#orange

# END OF SETTINGS ====================================================================================================================
## DO NOT CHANGE ANYTHING BELOW THIS LINE

DEBOUNCE_TIME = 0.05 #Seconds of delay after sampling the switches to allow for debouncing.
POLLING_RATE  = 0.02 #Delay in the main loop. Seconds between sampling the switches.

# --- Configure TRRS Pins ---
# Set TIP as a driven ground reference for external switches.
tip = digitalio.DigitalInOut(board.TIP)
tip.direction = digitalio.Direction.OUTPUT
tip.value = False # drive low (GND)

sleeve = digitalio.DigitalInOut(board.SLEEVE)
sleeve.direction = digitalio.Direction.INPUT
sleeve.pull = digitalio.Pull.UP

ring_2 = digitalio.DigitalInOut(board.RING_2)
ring_2.direction = digitalio.Direction.INPUT
ring_2.pull = digitalio.Pull.UP

ring_1 = digitalio.DigitalInOut(board.RING_1)
ring_1.direction = digitalio.Direction.INPUT
ring_1.pull = digitalio.Pull.UP

# This section sets the mode from memory on startup
if microcontroller.nvm[0] >= numModes: #If the stored value of mode is outside of the allowable range
    microcontroller.nvm[0]=0 # Reset stored value to the first mode
mode = microcontroller.nvm[0] # set the mode to the last stored value

gc.collect()

#Function Name: keystrokeCompiler
#       Inputs: A entry from the keystrokeMatrix, a list in the format [int, [keycode/mouseclick/mediacontrol]]
#      Outputs: None
#  Description: This function takes an entry from the keystroke matrix and uses it to send the corresponding entry
#               to the connected computer. It reads the first entry in the list to determine if it contains a keystroke,
#               mouse click, or a media control command, then sends each command in the second list to the connected computer.
def keystrokeCompiler(keystrokeEntry):
    # print("Compiling keystroke for entry: ", keystrokeEntry)
    key = keystrokeEntry[0] # this number says if its a keycode, mouse click, or media control
    code = keystrokeEntry[1] #this is the actual set of keycodes/mouse click/etc
    if key == 1:#if its a keystroke
        for e, i in enumerate(code):
            keyboard.press(code[e])#press every keystroke
        time.sleep(0.1)
        keyboard.release_all()#then release
    if key == 2:# if its a mouse click
        for e, i in enumerate(code):
            mouse.press(code[e])#click
        time.sleep(0.1)
        mouse.release_all()#then release
    if key == 3:#if its a media control
        for e, i in enumerate(code):
            cc.press(code[e])#press
        time.sleep(0.1)
        cc.release()#then release

#Function Name: setModeColour
#       Inputs: An integer representing the device mode
#      Outputs: None
#  Description: This function sets the colour of the TRRS NeoPixel. It takes the colourMatrix and uses the mode
#               to get the appropriate RGB list, and then sets the NeoPixel colour to those RGB values
def setModeColour(mode):#sets the neopixel colour based on mode
    pixel.fill(colourMatrix[mode])

#Function Name: incrementMode
#       Inputs: None
#      Outputs: None
#  Description: This function increases the mode by one. If the mode is greater than the number of modes, it resets
#               it to the first mode. The mode is then saved to non volatile memory and then updates the NeoPixel colour
def incrementMode():#move to the next mode
    global mode
    mode = mode + 1 #increase the mode
    if mode > (numModes-1): #if you go over the number of modes
        mode = 0 #start back at the beginning
    microcontroller.nvm[0]= mode #storing mode in memory to save between reboots
    setModeColour(mode) #update the LED
    # print("Mode:", mode)

#Function Name: switchDetection
#       Inputs: None
#      Outputs: An integer that represents the switch or combination of switches that is currently pressed.
#  Description: This function reads the value of the tip, ring 1, and sleeve of the TRRS jack. If any of them read low instead of high,
#               they have been pressed. Based on the combination of switches that have been pressed, it returns a value from 1-7. If no
#               switches have been pressed, it returns a value of 0
def switchDetection():
#    print("switchDetection")
    pressedSwitch = 0 #start with no switch pressed
    if (not ring_1.value) or (not ring_2.value) or (not sleeve.value): #if any of the switches have been pressed
        time.sleep(DEBOUNCE_TIME) #debounce
        if (ring_1.value) and (not ring_2.value) and (sleeve.value): #if just ring 2 switch pressed
            pressedSwitch = 1
        elif (not ring_1.value) and (ring_2.value) and (sleeve.value): #if just ring 1 switch pressed
            pressedSwitch = 2
        elif (ring_1.value) and (ring_2.value) and (not sleeve.value): #if just sleeve switch pressed
            pressedSwitch = 3
        elif (not ring_1.value) and (not ring_2.value) and (sleeve.value): #if ring 1 and ring 2 switches pressed
            pressedSwitch = 4
        elif (not ring_1.value) and (ring_2.value) and (not sleeve.value): #if sleeve and ring 1 switches pressed
            pressedSwitch = 5
        elif (ring_1.value) and (not ring_2.value) and (not sleeve.value): #if ring 2 and sleeve switches pressed
            pressedSwitch = 6
        elif (not ring_1.value) and (not ring_2.value) and (not sleeve.value): #if all switches pressed
            pressedSwitch = 7
    # print("pressedSwitch: ", pressedSwitch)
    return pressedSwitch

#Function Name: handleSwitch
#       Inputs: An integer that represents the switch or combination of switches that is currently pressed.
#      Outputs: None
#  Description: This function determines how long a switch has been held down and either switches the mode or sends a keystroke to the
#               keystrokeCompiler. When a button is first pressed, the LED is turned off. If it is held for more than the mode change time,
#               the LED will turn back on to indicate. When the switch is released, if it was held for more than the mode change time, the
#               mode will change and no other action will be taken. If it was held for less than the mode change time, it uses the mode and
#               the pressed switch to determine the correct entry from the keystrokeMatrix, and sends it to the keystrokeCompiler. Switches 6
#               and seven are currently unused, these switches are ignored if pressed.
def handleSwitch(inputSwitch):
    global mode
    if inputSwitch != 0:
        startTime = time.monotonic()#note the time when the switch was pressed
        pixel.fill((0, 0, 0))  # turn off led
        # print("Start Time: ", startTime)
        while switchDetection() == inputSwitch:#while the switch is pressed down
            if time.monotonic() - startTime > modeChangeTime: #if held for more than 4 seconds
                setModeColour(mode) #turn the LED back on
            time.sleep(0.5) # wait to give user time to release chorded switches
            continue
        endTime = time.monotonic()#note when switch was released
        # print("End Time: ", endTime)
        # print("Time Delta: ", (endTime - startTime))
        if endTime - startTime > modeChangeTime:#if held for more than 4 seconds
            incrementMode() #change the mode
            # print("Changing Mode")
        else:# if switch was not held for more than 4 seconds
            # print("Calling keystrokeCompiler with mode, switch: ", mode, ", ", inputSwitch)
            # currently throws error if 6 or 7 pressed, so filter them out
            setModeColour(mode)
            if (inputSwitch != 6) and (inputSwitch != 7): #ignore switch 6 or 7 since we don't use them
                keystrokeCompiler(keystrokeMatrix[mode][inputSwitch-1]) #send the appropriate HID packet
            else:
                keystrokeCompiler(keystrokeMatrix[mode][0])

setModeColour(mode)#on startup, activate the LED

while True: #main loop
    handleSwitch(switchDetection()) #check if a switch has been pressed
    time.sleep(POLLING_RATE)  # delay slightly so not constantly sampling

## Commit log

2025-07-25 Initial Commit
    Initial Commit of Shrub Hub Files
    [OpenAT_Placard.f3d, Shrub Hub Base.stl, Shrub Hub Enclosure.f3z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]
2025-07-28 Removed reference to PCB in ReadMe
2026-02-19 Added the V1.0 files
    Added all the V1.0 files
    [OpenAT_Placard.f3d, Shrub Hub Base.stl, Shrub Hub Enclosure.f3z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]
2026-02-23 Update README with validation testing details
    Added important information regarding final user and maker validation testing for the Shrub Hub device.
2026-02-25 updated user guide
    updated generating outputs with single switch section
2026-03-26 added link to device listing on MMC site
